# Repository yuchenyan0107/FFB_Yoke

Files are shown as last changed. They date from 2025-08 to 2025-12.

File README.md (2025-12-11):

# FFB_Yoke

## Overview
A 3D printable Force-Feedback Yoke for flight

Big thanks to Aggressorblue and other people from the VPForce Discord community. He integrated 8020 and Gantry into this design.

https://makerworld.com/en/models/1763788-ffb-yoke-case-revised-for-2080-gantry#profileId-1876684

More information regarding the electronic part and TelemFFB can be found in VPforce's documentation:

https://docs.vpforce.eu/community-projects/ffb-yoke/

I also made my own FFB software, FSFFB, largely inspired by the TelemFFB. It is currently for experimental purposes and overall a simplified version compared to TelemFFB, but with some features better tuned, for example, trim following and AP following support, and stall buffeting.
The goal of the FSFFB project is to use advanced aerodynamic methods (e.g., VEM) to build a realistic control loading model, while keeping the computational cost relatively low, which allows real-time simulation.

https://github.com/yuchenyan0107/FSFFB

**It's forbidden to sell any part or kit of this project, whether or not it is profitable, without my agreement.**

Modifications are welcome, but the only way to publicly distribute modified files (if you are going to distribute) is to make them publicly available and non-profitable.

## Key features

- Dual-axis FFB using VPforce 57BLF03 motors (pitch and roll axes)
- Linear rail gantry system (smooth Y-axis travel)
- Belt-driven mechanics with adjustable tension
- 3D printable components (PETG-CF/ABS recommended)
- Compatible with Honeycomb Alpha yoke handle (with adapter)
- Open-source design with active community development
- Reasonably priced DIY project for FFB yoke enthusiasts

## Component list

https://docs.google.com/spreadsheets/d/1nBpdCx0DOBi1BcTt7vbbc8EsOH5HXZhTVgTmGyhsMfY/edit?gid=0#gid=

| Category | Part | Spec | Qty/Note | UnitPrice |
| --- | --- | --- | --- | --- |
| center shaft | steel shaft | D 16mm, L 350mm | 1 | 3 |
| center shaft | STHWR 16 |  | 2 | 5 |
| center shaft | shaft clamp | 16mm | 1 | 3 |
| bearings | 608 |  | 2 | 0.50 |
| bearings | MR16287 |  | 1 | 3 |
| bearings | 6808 |  | 1 | 2 |
| linear rails | MGNR12 | 300mm | 2 | 5 |
| linear bearing | MGN12 C |  | 4 | 3 |
| pulleys | HTD 5M 12T | width 15mm, inner D 8mm | 2 | 2 |
| pulleys | HTD 5M belt | 750mm | 1 | 2 |
| pulleys | HTD 5M belt | 335mm | 1 | 1 |
| electric | potentiometer |  | 10k ohm | 1 |
| electric | emergency stop |  | 16mm | 2 |
| electric | 16 AWG |  |  | 1 |
| electric | micro JST XH | 2, 3, 5 pin & wire |  | 2 |
| electric | ALPS 8 way |  |  | 2 |
| Screws | M3*10 | M4*10 | M8*50 |  |
| Insert | M4 OD6 L6 | M3 OD5 L4 |  | 2 |

## Assembly Process Overview

**Important:** Before printing any parts, calibrate your printer regarding both the overall dimension and hole tolerance. Otherwise, the parts may not fit together.
When I built this with my Bambulab A1, I needed to set +0.6% for the x-axis, +0.3% for the y-axis, and -0.1mm for the holes.

Steps to install linear rails and bearings on the Y-axis gantry:

1. Screw two case bottom plates
2. Install two linear rails on the bottom plate; don’t tighten the screws.
3. Install bearing blocks on the linear rails (use the plastic guide rail while installing the bearing to prevent damage!)
4. Install the x_assembly bottom plate (without other parts) to the bearing blocks. Don’t make the screws very tight yet.
5. Slide the module on the linear rails back and forth while gradually tightening the screws on the linear rail and the bearing blocks. So that there’s minimal stress on the system
6. Unmount the bearing blocks and the x assembly plate from the linear rails, then finish the x-assembly
7. Install the x_assembly back to the linear rails, use the place guide rail to help with the installation.

Steps to assemble the Y-axis belt part to get good tension and smoothness

1. Mount the motor with 4 M6 bolts. Don't tighten them completely, because the motor needs to be moved backwards a little bit
2. Get the pulleys and belt installed. The belt doesn't need to be super tight at this moment. Just clamp it at a position 1 tooth before it's tensioned
3. Install the case plates (front, left side, back)
4. Use 2 M4 bolts to push the motor backwards to tension the belt. While tensioning the belt, move the gantry to feel the force needed to move it. The belt should be relatively tight, while not making too much additional friction, 
5. Tighten 4 of the M6 bolts that hold the motor

## Gallery

front view
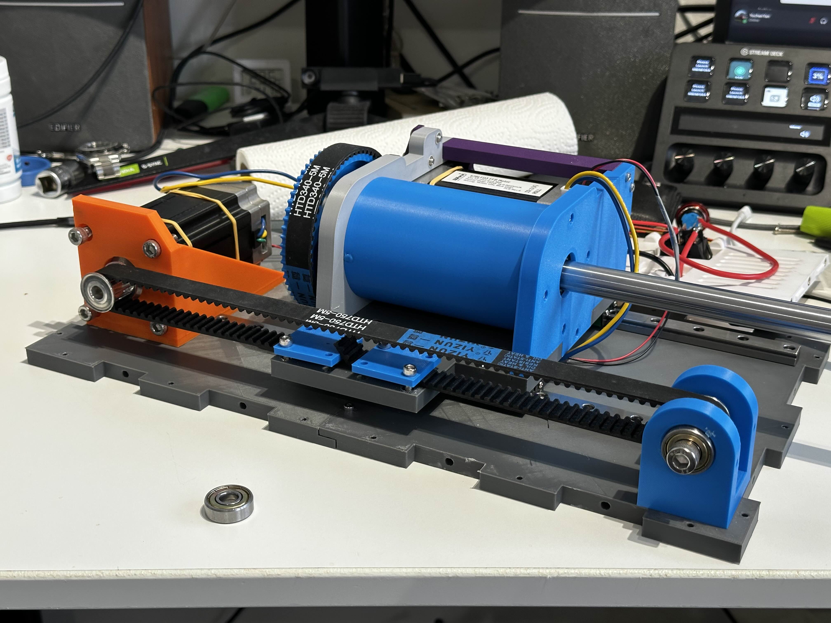
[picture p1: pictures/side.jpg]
picture from the side

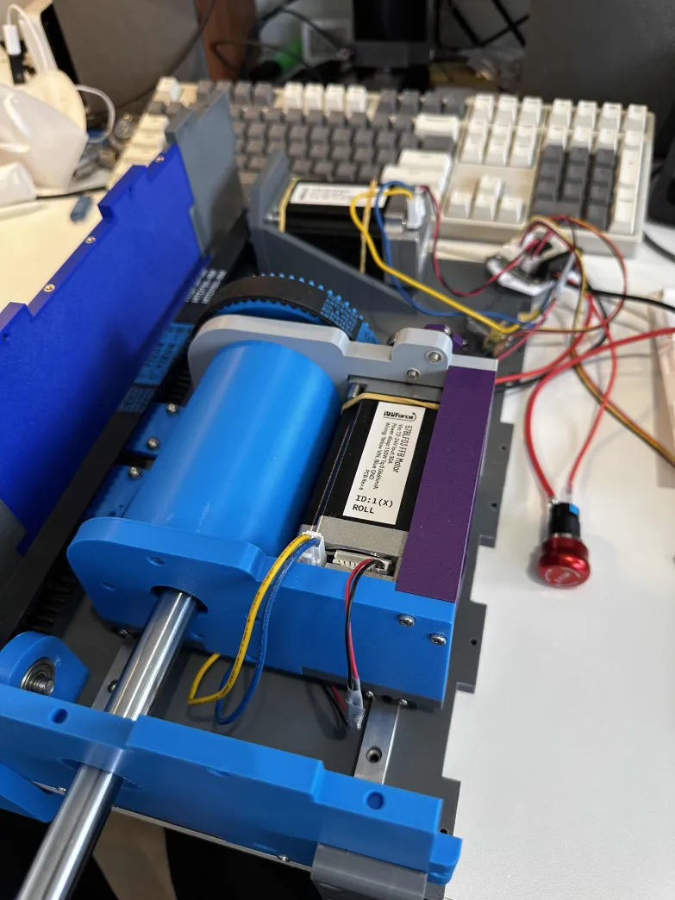
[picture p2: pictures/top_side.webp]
picture from the side

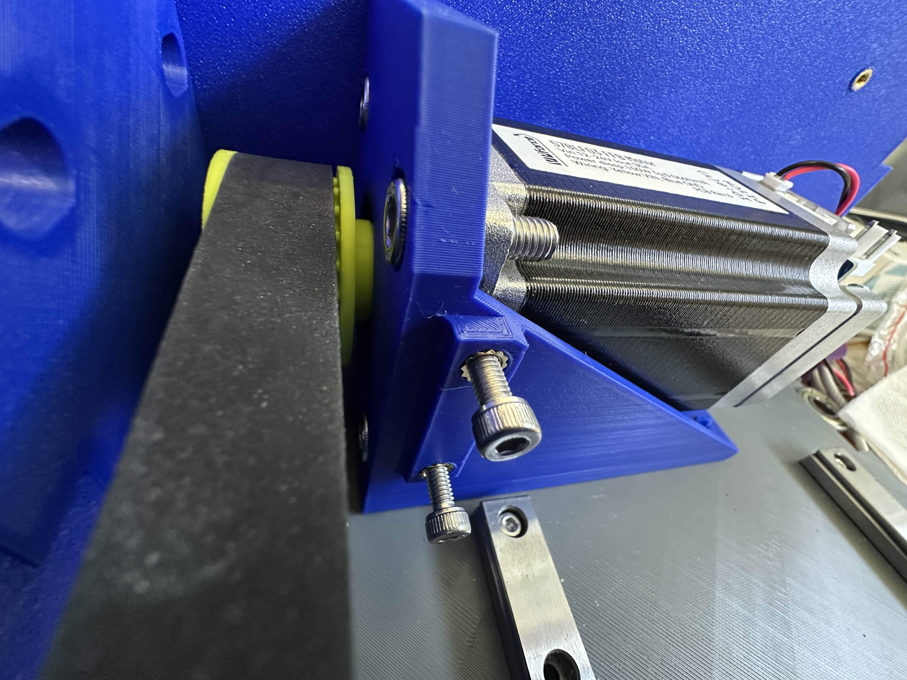
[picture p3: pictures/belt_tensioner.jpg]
Y_motor_belt


## Notes regarding VPforce setup and software

**Simulator Compatibility:**

- **MSFS:** Full TelemFFB support, trim following works with A2A aircraft (Comanche verified)
- **Advanced Airliner Add-ons in MSFS:** TelemFFB trim/AP following is not yet supported for PMDG, TFDI, and similar complex aircraft. Most of the modern airliners don't have trim following anyway.
- **X-Plane:** TelemFFB support available
- **DCS World:** DirectInput FFB support (and TelemFFB added to it). It works great with the C-130.

**Motor Range Considerations:**

- Yoke travel range exceeds 360° motor rotation
- **Critical:** Yoke must be positioned near center when powered on
- Motor range mapping accounts for extended yoke travel angles
- Does not require exact centering, but should be approximately centered on startup

!!! important "Power-On Position"
    Position yoke approximately in center position before powering on system. Yoke travel range corresponds to more than 360° of motor rotation, requiring centered startup for proper calibration.

**VKB/Virpil/Thrustmaster Grips:**

- Not applicable (yoke-specific design, not joystick grip compatible)

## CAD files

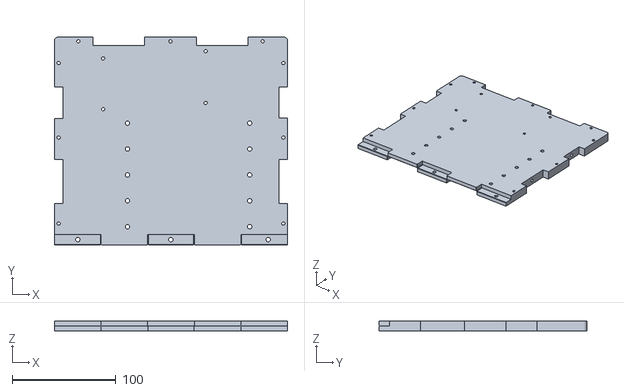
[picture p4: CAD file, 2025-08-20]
STL_files/Case/Case_bottom_rear.stl
225.0 x 200.5 x 10.0

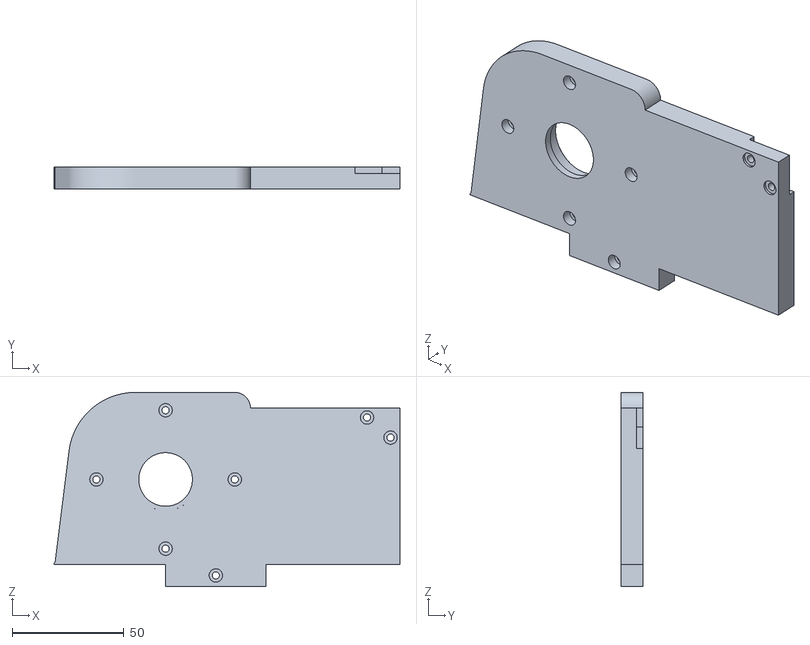
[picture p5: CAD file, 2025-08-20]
STL_files/X_assembly/Front.stl
155.0 x 10.00 x 87.0

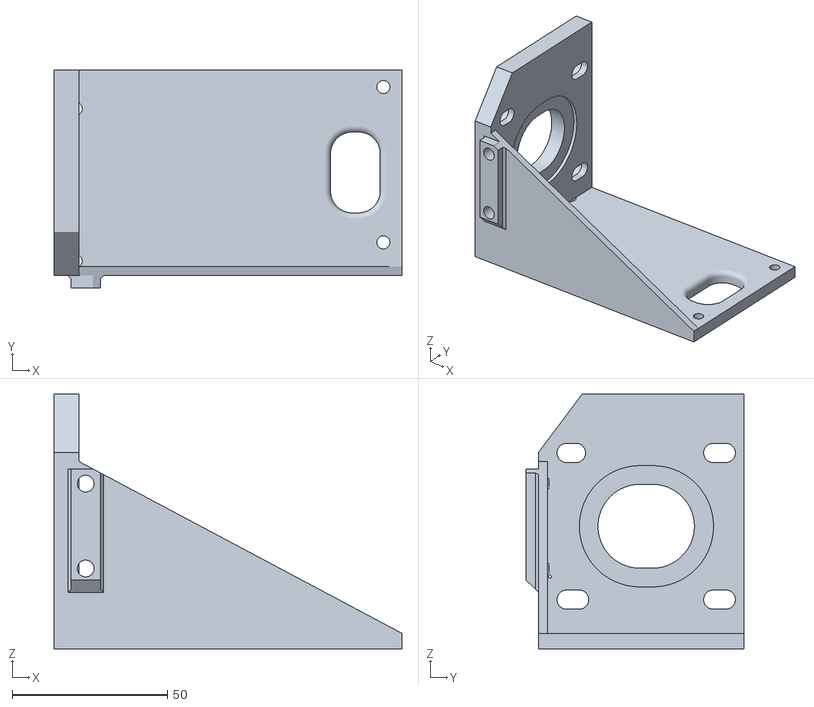
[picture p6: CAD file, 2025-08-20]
STL_files/Y_motor/Y_motor_mount .stl
112.0 x 70.2 x 82.0

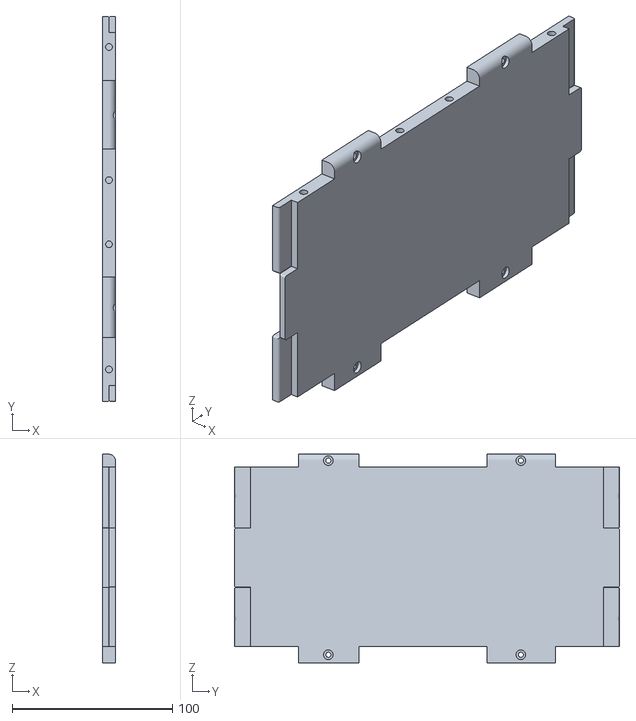
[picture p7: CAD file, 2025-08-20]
STL_files/Case/Case_right_center.stl
8.00 x 240.0 x 130.0

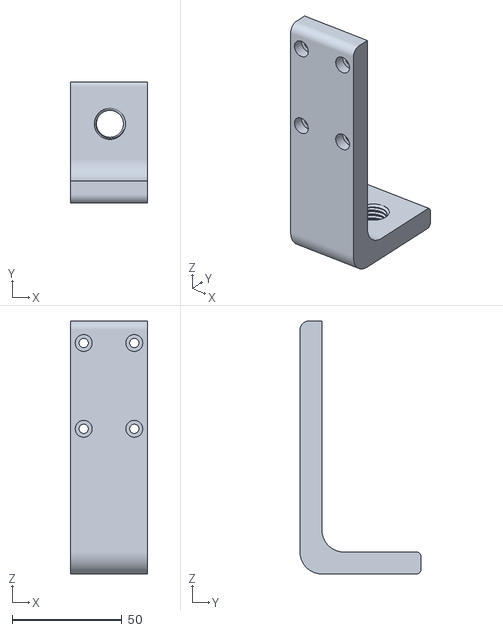
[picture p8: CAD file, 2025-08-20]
STL_files/Table_clamp/Table_clamp.stl
35.0 x 55.0 x 115.0

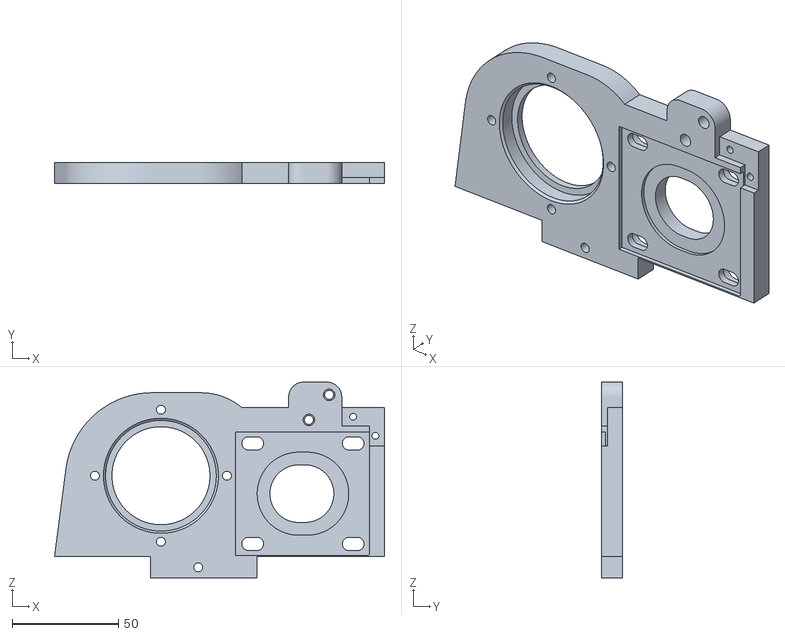
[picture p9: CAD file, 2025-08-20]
STL_files/X_assembly/Back.stl
155.0 x 10.0 x 92.0

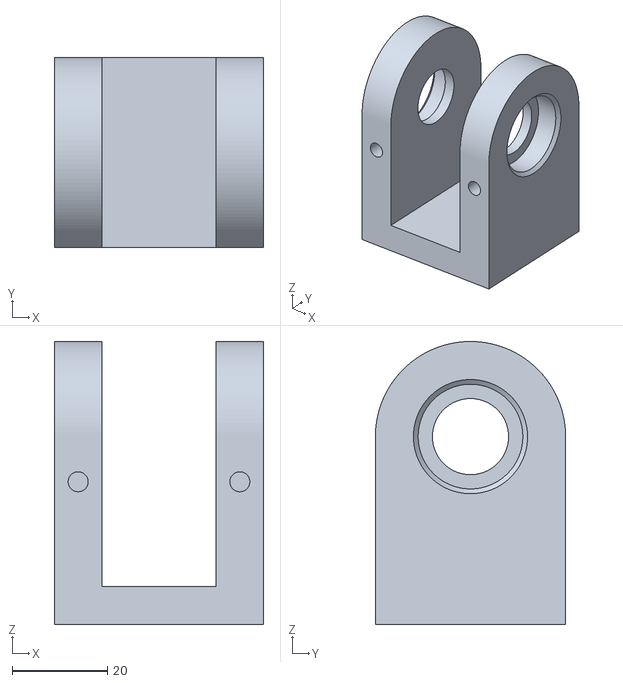
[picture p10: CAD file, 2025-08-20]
STL_files/Y_motor/Y_pulley_mount.stl
44.0 x 40.0 x 59.5

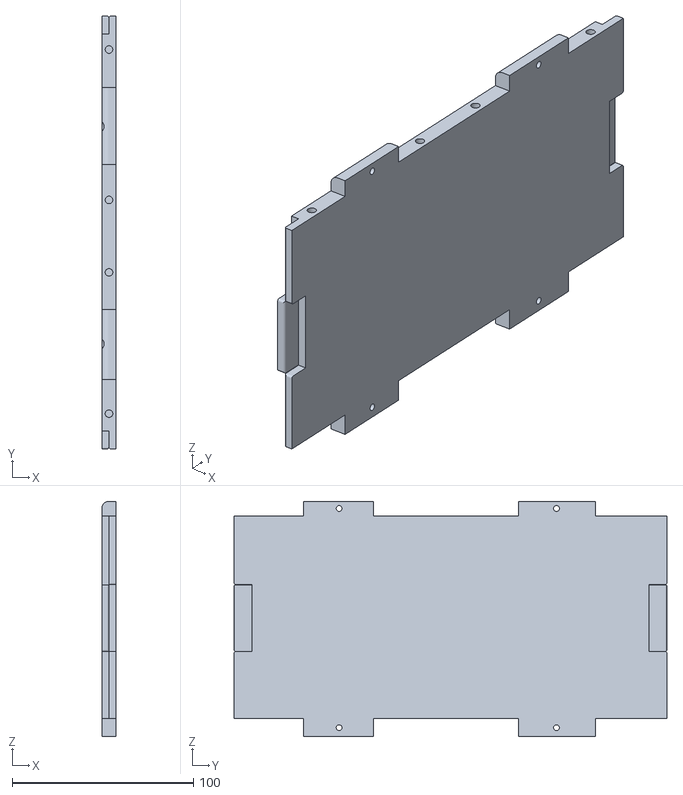
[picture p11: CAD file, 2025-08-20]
STL_files/Case/Case_left_center.stl
8.00 x 239.0 x 130.0

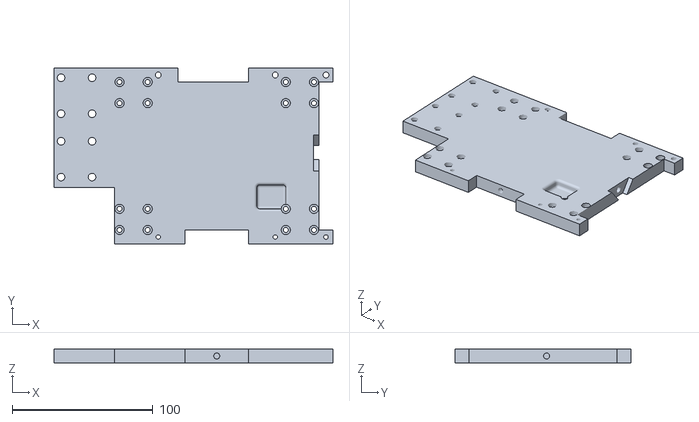
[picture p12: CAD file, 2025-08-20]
STL_files/X_assembly/Base.stl
198.0 x 125.0 x 10.0

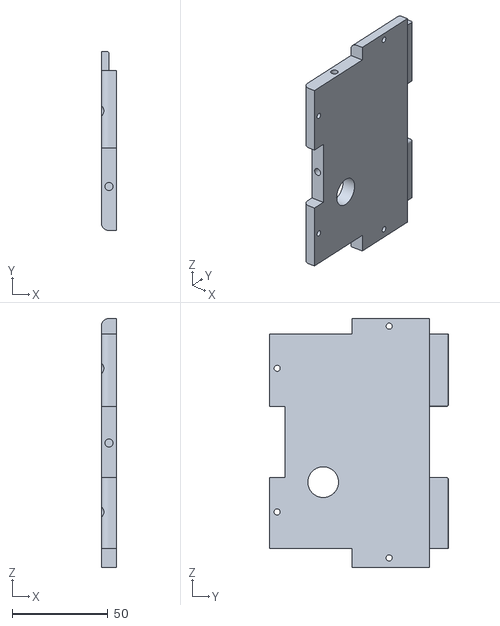
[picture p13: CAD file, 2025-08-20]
STL_files/Case/Case_left_front.stl
8.00 x 93.5 x 130.0

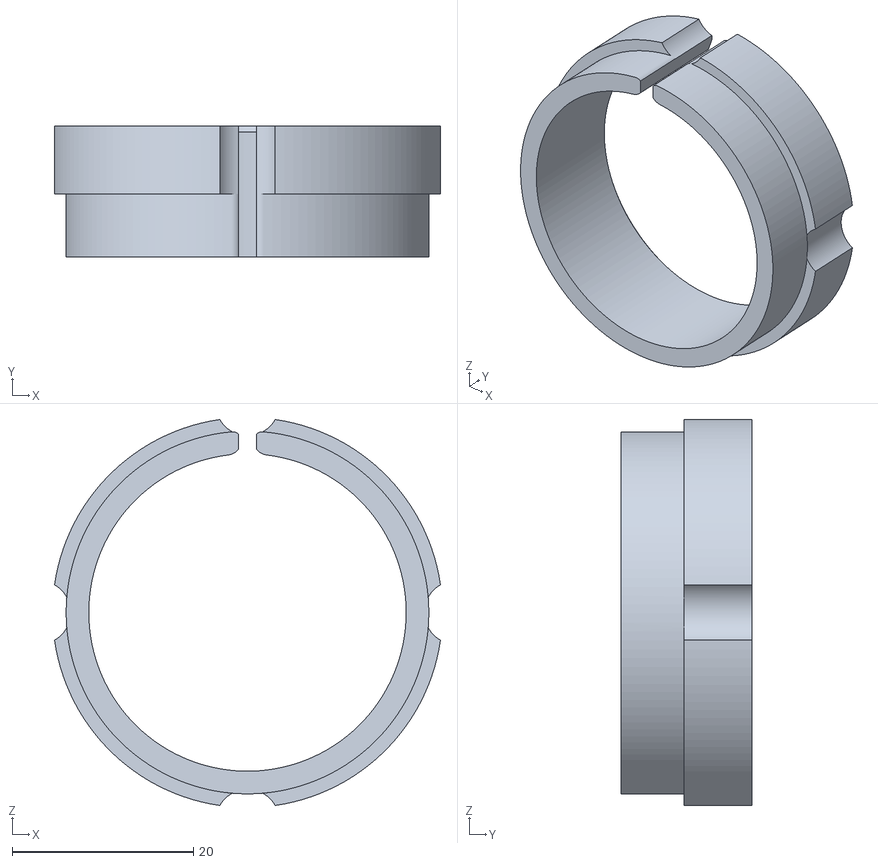
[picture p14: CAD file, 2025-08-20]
STL_files/X_assembly/Shaft_mount_1.stl
42.6 x 14.5 x 42.6

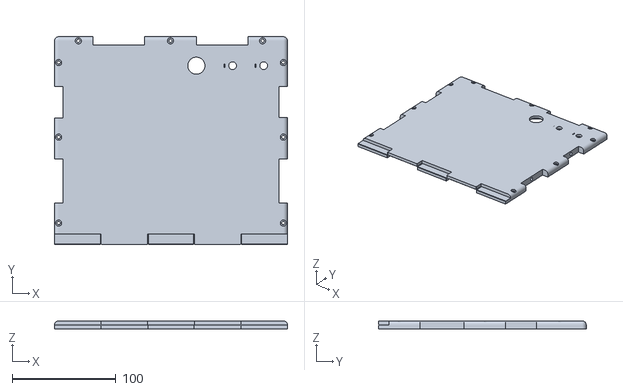
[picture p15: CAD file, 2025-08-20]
STL_files/Case/Case_top_rear.stl
225.0 x 200.5 x 8.00

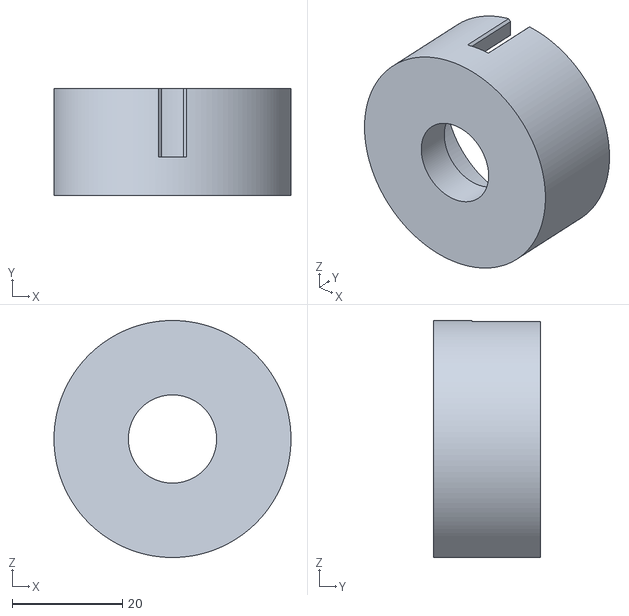
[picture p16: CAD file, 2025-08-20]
STL_files/X_assembly/Bearing_2.stl
43.0 x 19.5 x 43.0

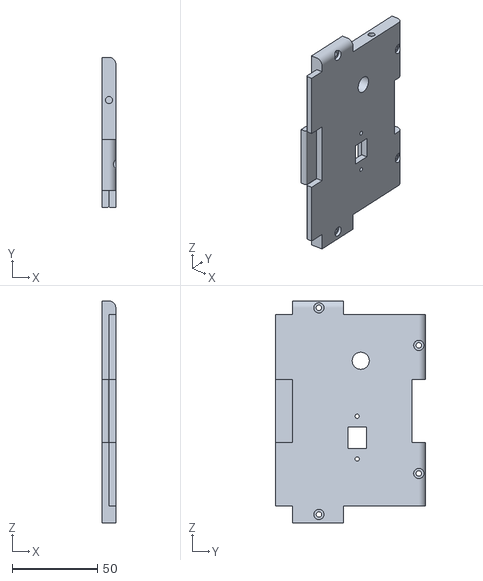
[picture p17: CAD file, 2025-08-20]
STL_files/Case/Case_right_rear.stl
8.00 x 88.0 x 130.0

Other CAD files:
STL_files/X_assembly/Mid.stl
STL_files/Case/Case_rear.stl
STL_files/X_assembly/Belt Clamp.stl
STL_files/Case/Case_bottom_front.stl
STL_files/Case/Case_front.stl
STL_files/Case/Case_left_rear.stl
STL_files/Case/Case_right_front.stl
STL_files/Case/Case_top_front.stl
STL_files/Table_clamp/Shaft_clamp_screw_washer.stl
STL_files/Table_clamp/Table_clamp_screw.stl
STL_files/X_assembly/Side.stl
STL_files/X_assembly/X_pulley_hub.stl
